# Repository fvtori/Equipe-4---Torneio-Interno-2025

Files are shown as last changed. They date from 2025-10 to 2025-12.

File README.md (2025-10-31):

# *Mini Sumô*

Robô desenvolvido para participar do Torneio Interno de Robôs na categoria “Mini Sumô”, organizado pelo projeto G.E.A.R..

## Estrutura do Projeto

Este registro descreve o processo de criação e desenvolvimento da Equipe 4, composta por cinco membros com as seguintes funções:

Fernanda — Gestora do projeto

Kirisawa — Veterano auxiliar, responsável pela parte técnica, estrutura e fluxo de montagem

Andresa — Programação

Luan — Eletrônica

Rebeca — Estrutura mecânica

## Organização dos Diretórios
```
CATEGORIA_DO_ROBÔ_ANO/
├── code/                       # Implementação da programação
│
├── docs/                       # Documentação do código
│
├── electronics/                # Eletrônica do projeto
│
├── mechanics/                  # Mecânica do projeto
│
├── misc/                       # Miscelânea
│
├── simu/                       # Simulação 
│
└── README.md --> ESTE ARQUIVO  # Resumo geral dos diretórios
```

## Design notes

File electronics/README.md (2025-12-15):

# Diretório de Eletrônica

Este diretório contém todos os arquivos relacionados ao projeto eletrônico do robô *(categoria do robô)*, incluindo:

- Esquemáticos eletrônicos  
- Diagramas de conexão  
- Lista de componentes (BOM)  
- Datasheets dos componentes  
- Registros de testes  
- Configurações de hardware  

---

## Estrutura

- `img/`: Pasta contendo imagens do projeto eletrônico  
  - Fotos das placas  
  - Diagramas de ligação  
  - Esquemáticos em protoboard/PCB  

---

## Documentação

Este README contém as instruções de uso, pinagem utilizada e explicação do circuito da versão atual do robô.

---

# Documentação da Parte Eletrônica — Mini Sumô (Jack)

O sistema eletrônico do robô **Jack**, desenvolvido pela **Equipe 4** para o **Torneio Interno de Robôs 2025** do projeto **G.E.A.R.**, é responsável pelo **controle, alimentação e acionamento dos motores** durante as partidas.

A eletrônica tem como objetivo principal permitir o **controle remoto via Bluetooth**, por meio de um **controle 8BitDo**, utilizando a biblioteca **Bluepad32** conectada à **ESP32 DevKit**.

Na versão atual do projeto, foi adotada novamente a **placa de expansão roxa da ESP32**, pois ela facilitou a organização das conexões e permitiu uma montagem elétrica **mais compacta**, adequada ao espaço reduzido do chassi do robô.

O sistema é alimentado por uma **bateria de lítio 2S (~7,4 – 7,8 V)**, responsável por fornecer energia tanto para os motores quanto para a parte lógica.

A **ponte H utilizada é a L298N**, responsável exclusivamente pelo **acionamento e controle dos motores DC**.

A **alimentação da ESP32 não é feita pela saída de 5V da L298N, como estava sendo feita antes**.  
A ESP32 é alimentada diretamente pela bateria através da **placa de expansão**, que possui **regulador onboard**, responsável por adequar a tensão de entrada aos níveis corretos de operação do microcontrolador.

Além disso, foi incluído no circuito um **módulo carregador de bateria de lítio**, permitindo a recarga da bateria sem a necessidade de desmontar o robô.

O sistema conta ainda com:
- um **interruptor (switch)** geral;
- um **fusível único** de proteção;
- um **buzzer** para sinalização sonora.

Os motores utilizados são **motores DC N20 com caixa de redução**, escolhidos por serem mais leves e compatíveis com o limite de peso da competição.

Essa versão representa a **arquitetura final da eletrônica do robô**, utilizada na fase de competição.

---

## ⚙️ Componentes Principais do Sistema Eletrônico

| Componente | Quantidade | Função no Circuito | Observações |
|---|---|---|---|
| **ESP32 DevKit** | 1 | Comunicação Bluetooth e controle do robô | Biblioteca Bluepad32 |
| **Placa de expansão roxa (ESP32 Expansion Board)** | 1 | Organização das conexões e regulação de tensão | Regulador onboard |
| **Ponte H L298N** | 1 | Controle dos motores DC | Dois canais independentes |
| **Motores DC N20 com redução** | 2 | Tração do robô | Leves e eficientes |
| **Bateria de lítio 2S (7,4 – 7,8V)** | 1 | Fonte de energia principal | Alimenta todo o sistema |
| **Módulo carregador de bateria** | 1 | Recarga da bateria | Integrado ao circuito |
| **Interruptor (switch)** | 1 | Liga/desliga geral | Corte total da alimentação |
| **Fusível** | 1 | Proteção elétrica | Protege a linha principal |
| **Buzzer** | 1 | Sinalização sonora | Controlado por GPIO |
| **Cabos e fios** | — | Interligações elétricas | Curtos e organizados |

---

## 🔌 Alimentação e Ligações de Energia

O robô **Jack** é alimentado por uma **bateria de lítio 2S (7,4 – 7,8V)**.  
A distribuição de energia é feita de forma direta e compacta utilizando a **placa de expansão da ESP32**.

### 🔋 Caminho da alimentação

1. **Bateria 2S (7,4 – 7,8V)**  
2. **Interruptor (switch)**  
3. **Placa de expansão da ESP32**  
4. Distribuição da energia para:
   - ESP32 (via regulador onboard)
   - Ponte H L298N
   - Demais periféricos

Todos os módulos compartilham **GND comum**, condição essencial para o correto funcionamento dos sinais de controle.

---

## 🔒 Fusível (Proteção)

O circuito utiliza **um único fusível**, instalado após o switch, responsável por proteger a alimentação principal e a ponte H contra curto-circuito e sobrecorrente.

---

## 🧠 Resumo da Alimentação

| Elemento | Alimentação |
|---|---|
| ESP32 | 7,4 – 7,8V (via placa de expansão) |
| Ponte H L298N | 7,4 – 7,8V |
| Motores N20 | 7,4 – 7,8V |
| Buzzer | Linha lógica |
| Módulo carregador | Conectado à bateria |

---

## 🧩 Pinagem e Conexões Lógicas — ESP32 + L298N

As conexões lógicas entre a **ESP32** e a **ponte H L298N** seguem o mapeamento abaixo.

---

### 🔵 Canal A — Motor Esquerdo

| Ponte H | GPIO ESP32 | Função |
|---|---|---|
| ENA | GPIO 23 | PWM (velocidade) |
| IN1 | GPIO 19 | Direção |
| IN2 | GPIO 18 | Direção |

---

### 🔴 Canal B — Motor Direito

| Ponte H | GPIO ESP32 | Função |
|---|---|---|
| ENB | GPIO 22 | PWM (velocidade) |
| IN3 | GPIO 5 | Direção |
| IN4 | GPIO 21 | Direção |

---

### 🔔 Buzzer

| Componente | GPIO ESP32 | Função |
|---|---|---|
| Buzzer | GPIO 32 | Sinalização sonora |

---

## ⚡ Observações Importantes

- ENA e ENB utilizam **PWM** para controle de velocidade.
- IN1 a IN4 definem o sentido de rotação dos motores.
- O buzzer é utilizado para sinalizar quando o controle conecta na esp32
- O compartilhamento de **GND comum** é essencial para o funcionamento correto do sistema.

---

## 📌 Resumo Rápido da Pinagem

| Componente | GPIO |
|---|---|
| ENA | 23 |
| IN1 | 19 |
| IN2 | 18 |
| ENB | 22 |
| IN3 | 5 |
| IN4 | 21 |
| Buzzer | 32 |

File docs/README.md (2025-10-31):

# **docs**
Este diretório tem como objetivo documentar o projeto do código do robô do seu grupo. É o relatório de todo o projeto.

O código implementado pode ser visto em: [`code`](../code).
## **Introdução**

O projeto se trata de um robô *(categoria do robô)* de alto desempenho utilizado para a competição *(nome da competição)*.

<!-- *Imagem/ do robô* -->
<!-- ![Nome do robô](img/nome_do_arquivo_de_imagem.png)  -->

*Figura 1: *(categoria do robô)**

## **1. Bill of Materials (BOM)** 

**(*Apenas um exemplo, adicionar coisas como motor, microcontrolador, pneu, etc*)**

Na tabela a seguir será possível observar a lista com todos os componentes físicos utilizados para a construção do robô *(categoria do robô)*:

| 	| **Bill of Materials - BOM** 	| 	|
|:---:	|:---:	|:---:	|
| Nome 	| Explicação 	| Quantidade 	|
| 	| **Baterias e componentes relacionados** | 	|
| Bateria X 	| Bateria do robô 	| qtd 	|
| 	| **Componentes eletrônicos** 	| 	|
| Sensor X 	| Sensor para X coisa 	| qtd 	|
| Componente Y 	| Componente para Y coisa | qtd 	|

## **2. Modelagem 3D**

*Inserir imagens e explicações da [modelagem 3D](../mechanics)*.

## **3. Esquemático eletrônico**

*Inserir imagens e explicações do [circuito eletrônico](../electronics)*.

## **4. Arquitetura geral do diretório raiz**

- **[/code](../code)** — Código-fonte do robô: firmware, bibliotecas, scripts de build e exemplos de execução.
- **[/docs](../docs)** — Documentação do projeto: relatórios, manuais, diagramas e este README.
- **[/eletronics](../eletronics)** — Esquemáticos, listas de componentes (BOM), layouts de PCB e notas de montagem.
- **[/mechanics](../mechanics)** — Modelos 3D, desenhos CAD, arquivos de impressão/usinagem e instruções de montagem mecânica.
- **[/misc](../misc)** — Arquivos diversos: qualquer arquivo que não se enquadram nas demais pastas. (editais, planilhas, etc)
- **[/simu](../simu)** — (OPCIONAL) Cenários de simulação, scripts de execução e automação, ferramentas de visualização.

Cada pasta contém um README interno com instruções específicas de uso, dependências e explicações específicas.

## **5. Organização do Fluxo do Robô (Exemplo)**

1. **Setup:**
    - Inicializar sensores, motores, PID, e conexão remota.

2. **Loop Principal: (Exemplo)**
    - Ler sensores.
    - Calcular o erro da linha.
    - Ajustar a velocidade com o PID.
    - Detectar faixas indicativas e curvas.
    - Analisa eventos para mapeamento.
    - Enviar dados para telemetria.
    
3. **Comunicação Bluetooth:**
    - Escutar comandos remotos para ajuste do PID.
    - Enviar dados em tempo real.

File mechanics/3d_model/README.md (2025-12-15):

# Modelagem do Robô

Este documento descreve o modelo mecânico do robô, apresentando as peças desenvolvidas, suas funções e a estrutura geral do conjunto.

---

## 1. Modelo Inicial

O modelo inicial é composto por um chassi que abriga dois motores de alto torque (JGA), conectados a duas rodas por meio de engrenagens cônicas. A transmissão do movimento e a fixação das rodas utilizam um conjunto formado por bucha, arruela, rolamento e parafuso.

### Função de Cada Componente

- **Base (Chassi):**
<div align="center">
  
</div>

  Abriga motores, rodas e partes do sistema de transmissão.

- **Engrenagem Cônica:**
  
<div align="center">
  
 </div>

  Transmite o movimento do motor para a roda que mantêm uma relação de 90°.

- **Bucha:**

  <div align="center">
  
  </div>
  
  Mantém o espaçamento correto entre o rolamento e a parede interna do chassi.

- **Arruela:**
  
  <div align="center">
  
  </div>

  Auxilia na fixação e na distribuição da carga da roda.

- **Rolamento:**
  <div align="center">
    
 </div>

  Permite o giro suave da roda e conecta o eixo ao conjunto de engrenagem.

- **Montagem:**
  <div align="center">
    
  </div>

  Montagem completa da base
- **Rampa:**
  <div align="center">
    
     </div>

O modelo conta com um protótipo de rampa na parte frontal, integrada ao chassi, projetada para auxiliar o robô durante seu deslocamento e interação com obstáculos.

---

## 2. Montagem Final

Após a mudança do motor JGA para o N20, foi necessário modificar a base a fim de atender aos requisitos do sumô. 
O chassi abriga dois motores de torque médio (N20), conectados a duas rodas. É composto por duas camadas: a primeira camada envolve os motores, as rodas e a case de pilhas, enquanto a segunda acomoda a ponte H, a placa de expansão da ESP32 e a própria ESP 32. A rampa se manteve a mesma.

- **Primeira camada (Base do chassi):**
   <div align="center">
     
     </div>

  Abriga motores, rodas e case.

- **Segunda camada:**
   <div align="center">
     
     </div>

  Abriga ponte H e placa de expansão.

- **Montagem completa:**
   <div align="center">
     
     </div>

- Primeira camada
<div align="center">
  
</div>

- Segunda Camada vista por baixo
<div align="center">
  

</div>

## 3. Arquivo de Montagem

A visualização completa do robô montado pode ser encontrada em:

**`Montagem.iam`**

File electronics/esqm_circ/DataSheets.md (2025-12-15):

# 📄 Datasheets — Componentes do Circuito Eletrônico Oficial  
## Robô Mini Sumô Jack (Equipe 4 — G.E.A.R.)

Este documento reúne os *datasheets e referências técnicas oficiais* dos componentes utilizados no *circuito eletrônico final* do robô *Jack*.

Os links apresentados servem como base para:
- consulta técnica;
- verificação de limites elétricos;
- especificações de pinagem;
- futuras manutenções ou melhorias no projeto.

---

## 📑 Lista de Datasheets

| Componente | Datasheet / Referência Técnica |
|---|---|
| *ESP32 DevKit (ESP32-WROOM)* | https://www.mouser.com/datasheet/2/891/esp-wroom-32_datasheet_en-1223836.pdf |
| *Placa de Expansão ESP32 (Expansion Board)* | https://handsontec.com/dataspecs/module/ESP/ESP32%20Expansion%2030P.pdf |
| *Ponte H L298N* | https://www.handsontec.com/dataspecs/L298N%20Motor%20Driver.pdf |
| *Motor DC N20 com redução* | https://www.pololu.com/file/0J1487/n20-micro-metal-gearmotors.pdf |
| *Bateria de lítio 2S (Li-ion / LiPo)* | |
| *Módulo carregador de bateria de lítio (TP4056)* | https://www.circuits-diy.com/tp4056-battery-charger-module/ |
| *Buzzer ativo 5V* | https://www.farnell.com/datasheets/2171929.pdf |
| *Interruptor (Switch ON/OFF)* | https://components101.com/switches/spst-rocker-switch-non-illuminated |
| *Fusível (vidro / automotivo)* | https://pt.scribd.com/document/430928597/a90-fusiveis-termicos|

---

## 📌 Observações

- Alguns componentes (como motores N20, buzzers e interruptores) possuem *variações de fabricante*.  
  Os datasheets listados representam *modelos equivalentes amplamente utilizados*.
- Este arquivo complementa:
  - README.md — funcionamento e arquitetura do circuito  
  - BOM.md — lista oficial de materiais  
  - historico_circuitos.md — evolução do circuito eletrônico

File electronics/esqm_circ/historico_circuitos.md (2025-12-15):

# Histórico de Desenvolvimento do Circuito — Robô Jack

Este documento mostra a evolução do circuito eletrônico do robô **Jack**, desde as primeiras versões de teste até o modelo final utilizado na competição.

---

### 🧪 Circuito Teste 1

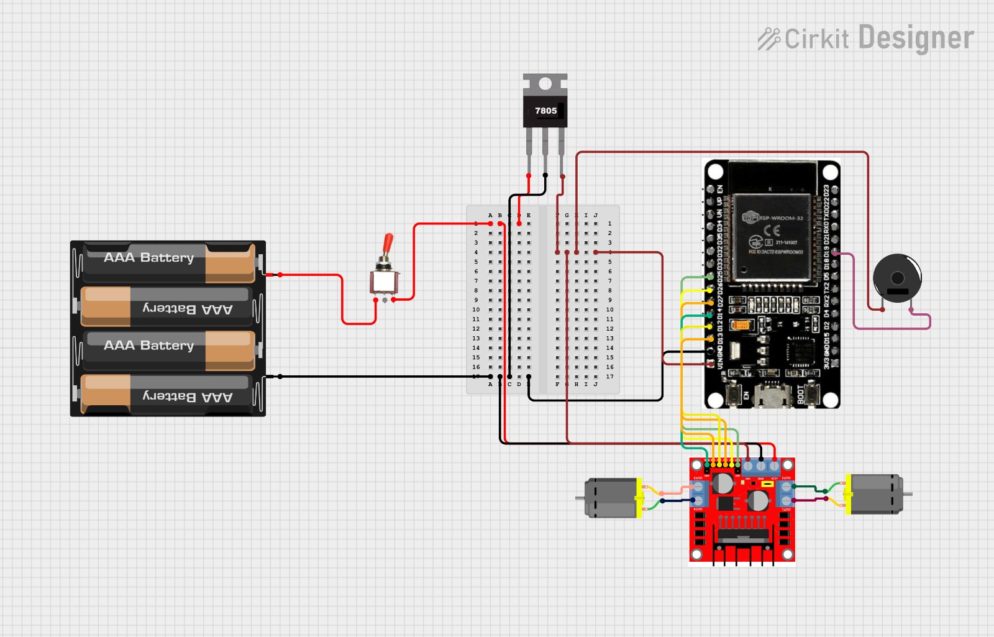
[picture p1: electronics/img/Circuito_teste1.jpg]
Circuito introdutório - versão inicial


O primeiro circuito desenvolvido para o robô **Jack** teve como principal finalidade **representar conceitualmente o sistema eletrônico** do projeto.  
Nesta etapa, ainda não foram realizados testes práticos, com o objetivo sendo apenas **visualizar e planejar** como seria feita a distribuição de energia e o controle básico dos motores.

A proposta dessa montagem foi criar uma **referência visual** que ajudasse a equipe a entender o caminho da alimentação e a função de cada componente, antes de partir para a execução real do protótipo.

#### 🧩 Estrutura e componentes representados
- **Case de 4 pilhas AAA**: escolhido inicialmente para fornecer aproximadamente **9 V**, simulando uma fonte simples e acessível.  
- **Chave liga/desliga (switch)**: adicionada para representar o controle manual de energia.  
- **Regulador de tensão 7805**: responsável por reduzir a tensão de 9 V para 5 V, garantindo segurança à ESP32.  
- **Protoboard**: utilizada como base para a montagem ilustrativa, permitindo visualizar o trajeto dos fios e conexões.  
- **Ponte H (L298N)**: incluída para simular o controle bidirecional dos dois motores DC.  
- **Buzzer**: adicionado como indicação sonora de funcionamento.  
- **ESP32**: microcontrolador principal, representando o núcleo lógico do sistema.

#### 🎯 Objetivo da versão
O propósito desta primeira versão foi **explorar visualmente a arquitetura elétrica** do robô, definindo:
- Como a energia fluiria desde o case de pilhas até a ESP32;  
- Onde seriam posicionados os componentes principais;  
- E como os motores e o buzzer seriam integrados ao controle lógico.

---

### ⚙️ Circuito Teste 2 — Planejamento para Transição à PCB

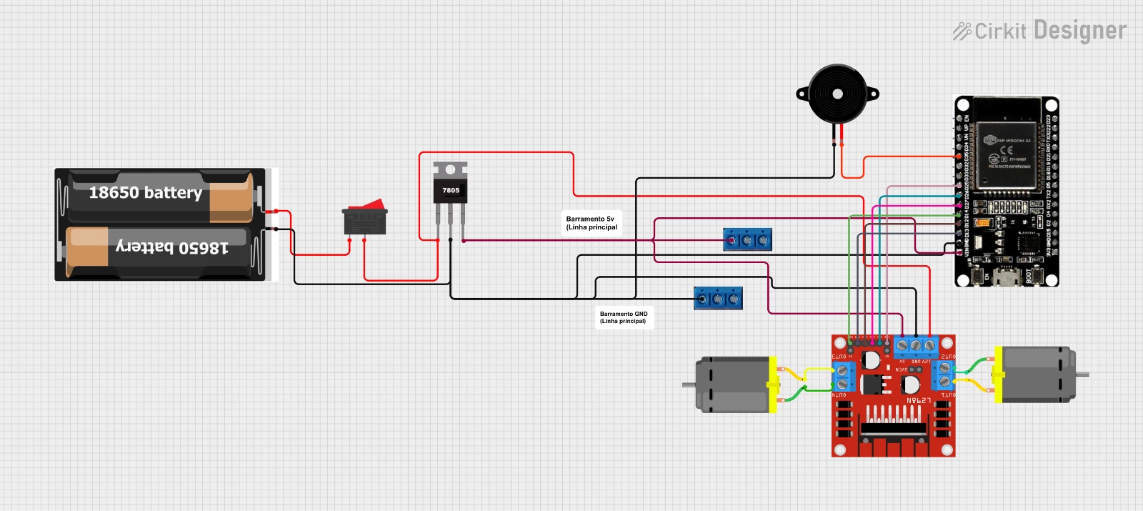
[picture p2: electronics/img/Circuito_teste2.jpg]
Circuito Teste 2


Nesta segunda etapa, a equipe buscou **aperfeiçoar o planejamento elétrico** do robô **Jack**, avançando do modelo conceitual inicial para uma proposta **mais estruturada e realista**.  
A principal mudança foi a **intenção de substituir o uso da protoboard por uma placa PCB personalizada**, onde os componentes seriam soldados, garantindo maior confiabilidade durante a competição.

O esquema apresentado representa esse novo conceito de organização e distribuição de energia. Embora o circuito não tenha sido montado fisicamente, ele serviu como **base de estudo para o design da futura placa**.

#### 🔧 Estrutura e componentes representados
- **Bateria 18650 (2 unidades em série)**: substituiu o antigo case de pilhas AAA, fornecendo uma **tensão nominal de 7,4 V** e maior autonomia.  
- **Chave liga/desliga (switch)**: manteve-se como controle principal de alimentação.  
- **Regulador de tensão 7805**: responsável por fornecer **5 V estáveis** para o circuito lógico.  
- **Barramentos VCC e GND**: representados pelos terminais azuis, planejados para fazer parte da futura **PCB**, permitindo a distribuição de energia de forma organizada e segura.  
- **Ponte H (L298N)**: utilizada para controle dos dois motores DC.  
- **Buzzer**: mantido como dispositivo sonoro auxiliar.  
- **ESP32**: microcontrolador principal, responsável pela lógica e controle dos motores.  

#### 🎯 Objetivo da versão
O objetivo desta fase foi **planejar a implementação física definitiva do circuito**, simulando:
- A disposição dos componentes sobre a placa;  
- A criação de **barramentos integrados de 5 V e GND**;  
- A eliminação de fios soltos e conexões instáveis típicas de protoboards.  

A ideia era que a futura PCB concentrasse **toda a parte elétrica principal**, incluindo a ESP32, o regulador, os conectores dos motores e o buzzer.

#### ⚙️ Desafios e decisões
Apesar de o conceito ser promissor, a equipe identificou algumas dificuldades práticas:
- O **tamanho da placa** seria considerável, aumentando o peso e a complexidade do robô;  
- O **processo de soldagem** exigiria tempo e precisão elevados;  
- O número de fios e trilhas seria grande, o que aumentava a chance de erro e dificultava a manutenção.

Esses fatores levaram à decisão de **não prosseguir com o uso da PCB** neste estágio, concentrando esforços em buscar uma solução mais compacta e funcional para a alimentação e distribuição de energia.

---

### ⚙️ Circuito Teste 3 — Implementação de Proteções e Uso do Expansor da ESP32

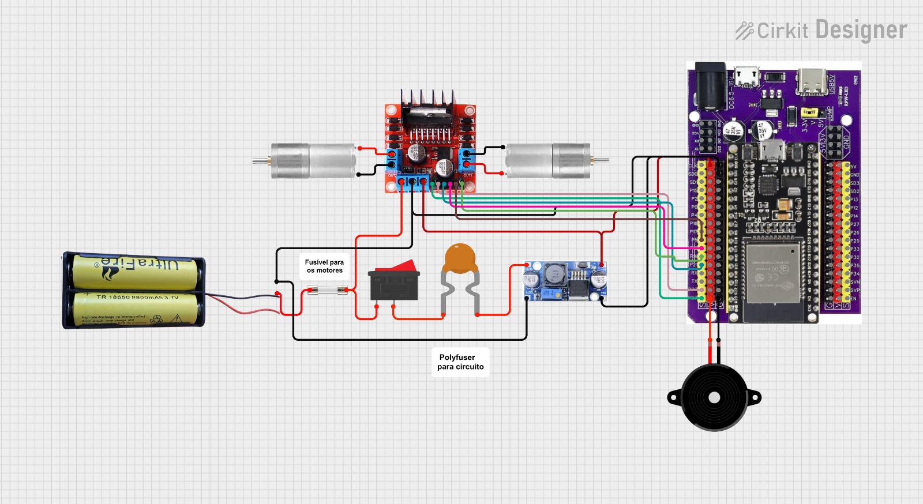
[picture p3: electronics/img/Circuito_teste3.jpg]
Circuito Teste 3


O **Circuito Teste 3** marcou uma das maiores evoluções no projeto eletrônico do robô **Jack**.  
Nesta versão, a equipe focou em **otimizar o espaço físico, melhorar a segurança elétrica e reduzir a quantidade de fios**, aproximando o design do formato que seria utilizado no protótipo final.

Diferente das versões anteriores, este circuito já apresenta uma **configuração mais realista e organizada**, com elementos de proteção e componentes atualizados conforme a disponibilidade no laboratório G.E.A.R.

#### 🔧 Principais mudanças e melhorias
- **Regulador de tensão LM2596:** substituiu o antigo **7805**, já que este não estava disponível no laboratório. O LM2596, além de ser **ajustável e mais eficiente**, dissipa menos calor e garante maior estabilidade.  
- **Interruptor compacto:** adotado no lugar da chave *switch* tradicional, oferecendo **menor consumo de espaço** e melhor integração ao corpo do robô.  
- **Duas medidas de proteção:**  
  - **Fusível** entre a bateria e a **ponte H**, evitando sobrecorrente nos motores;  
  - **Polyfuse (PTC resetável)** em série com o circuito lógico, protegendo a **ESP32 e o regulador** contra curtos e aquecimentos.  
- **Expansor da ESP32:** substituiu a placa simples, funcionando como **protoboard integrada**, o que **reduziu a quantidade de fios** e **facilitou as conexões** de sensores e drivers.  
- **Buzzer** mantido como componente auxiliar de sinalização, agora ligado diretamente ao expansor.

#### 🔋 Organização da alimentação
O novo arranjo manteve o uso de **duas baterias 18650 (7,4 V totais)** como fonte principal, agora com melhor distribuição:
1. A energia passa primeiro pelo **interruptor principal**;
2. Em seguida, é direcionada ao **fusível dos motores** e ao **polyfuse do circuito lógico**;
3. O **regulador LM2596** reduz a tensão para o valor ideal da ESP32 e demais módulos.

Essa configuração tornou o sistema mais seguro, evitando riscos de sobrecarga e incêndio — um passo importante para garantir confiabilidade durante o torneio.

#### ⚙️ Considerações do design
Além das melhorias elétricas, esta versão trouxe uma grande vantagem mecânica: a **eliminação da protoboard**.  
Com o expansor da ESP32, todas as conexões ficaram mais firmes, reduzindo o risco de mau contato e simplificando o layout geral do robô.  

A equipe também pôde visualizar de forma mais clara a **separação das linhas de potência e lógica**, o que facilita futuras manutenções e diagnósticos.

---

### ⚙️ Circuito Teste 4 — Compactação Máxima e Uso de Placas de Servo como Drivers

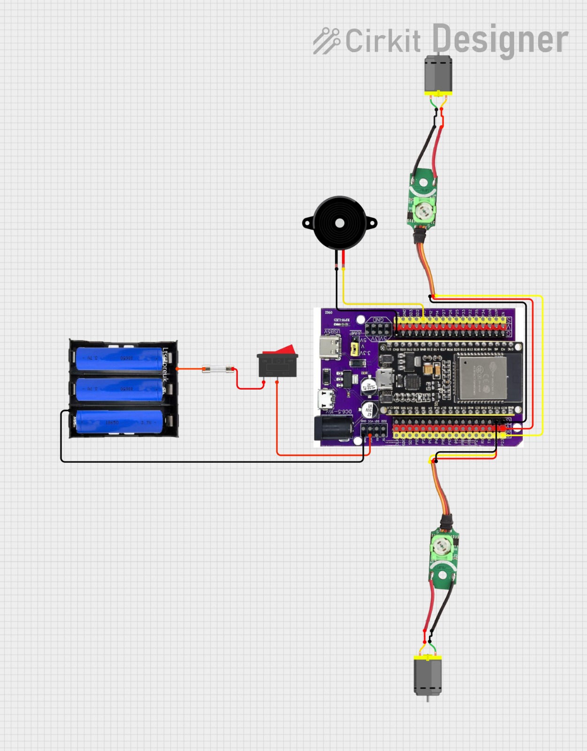
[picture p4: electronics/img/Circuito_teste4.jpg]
Circuito Teste 4


O **Circuito Teste 4** foi desenvolvido como uma tentativa de **reduzir ao máximo o peso e o volume da eletrônica**, priorizando simplicidade e integração direta com o chassi do robô **Jack**.  
Nesta versão, a equipe buscou eliminar componentes considerados intermediários e avaliar soluções alternativas para o acionamento dos motores.

Diferente das versões anteriores, este circuito foi **montado e testado integralmente**, permitindo observar o comportamento real do sistema sob carga.

#### 🔧 Principais mudanças em relação ao Circuito Teste 3
- **Remoção completa do regulador externo (LM2596):** a alimentação passou a utilizar exclusivamente o **regulador onboard da placa de expansão da ESP32**, reduzindo peso e número de componentes.  
- **Alimentação direta no expansor:** o positivo e o GND da bateria foram ligados diretamente aos **pads inferiores da placa de expansão**, simplificando o caminho da energia.  
- **Substituição da ponte H:** a L298N foi removida e substituída por **duas placas de servo modificadas**, cada uma responsável por acionar um motor DC.  
- **Redução de cabeamento:** com menos módulos intermediários, o circuito passou a utilizar fios mais curtos e em menor quantidade.  

#### 🧩 Estrutura do circuito nesta versão
- **Case de 3 pilhas AA**, utilizado como fonte de energia nesta etapa de testes;  
- **Interruptor liga/desliga**, responsável por energizar todo o sistema;  
- **Placa de expansão roxa da ESP32**, centralizando alimentação e sinais;  
- **ESP32 DevKit**, responsável pelo controle lógico;  
- **Duas placas de servo modificadas**, atuando como drivers simples de motor;  
- **Dois motores DC com redução**, utilizados para ensaios de tração;  
- **Buzzer**, mantido para sinalização sonora.

#### 🔋 Organização da alimentação
A alimentação seguiu uma topologia direta e simplificada:
1. A energia das pilhas passa pelo **interruptor principal**;  
2. O positivo e o GND são conectados diretamente aos **pads da placa de expansão**;  
3. O regulador onboard do expansor fornece as tensões necessárias para a ESP32;  
4. Drivers e buzzer compartilham o **GND comum** do sistema.

#### ⚠️ Limitações observadas nos testes
Apesar de o circuito apresentar funcionamento elétrico estável, os testes práticos revelaram uma limitação crítica:

- As **placas de servo modificadas não forneceram corrente suficiente** para os motores DC;  
- O sistema apresentou **baixo torque**, especialmente em situações de maior carga;  
- O desempenho obtido seria insuficiente para aplicações de **mini-sumô**, onde força e resposta rápida são essenciais.

Devido a essas limitações, o **Circuito Teste 4 não foi adotado como solução final**, servindo apenas como etapa experimental.

#### ⚙️ Considerações finais desta etapa
O Circuito Teste 4 foi importante para demonstrar que:
- A **compactação extrema da eletrônica é viável**, desde que os drivers sejam adequados;  
- O uso de soluções reaproveitadas (como placas de servo) pode funcionar em testes leves, mas **não atende às exigências mecânicas da competição**;  
- A escolha do driver de motor é determinante para o desempenho global do robô.

Os aprendizados obtidos nesta versão direcionaram a equipe para uma solução mais robusta na etapa seguinte do projeto.

---

### ⚙️ Circuito Teste 5 — Retorno à Ponte H e Reorganização para Redução de Peso

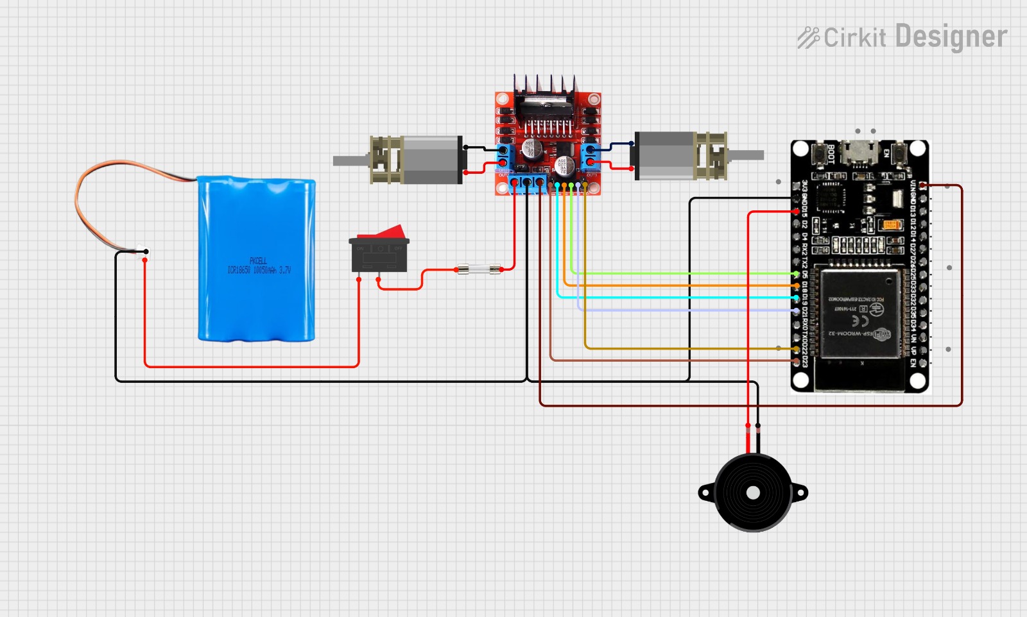
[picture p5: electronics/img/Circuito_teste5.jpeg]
Circuito Teste 5


O **Circuito Teste 5** marca a transição definitiva para uma solução **mais robusta de acionamento dos motores**, corrigindo as limitações observadas no Circuito Teste 4.  
Nesta etapa, a equipe realizou mudanças estruturais importantes, motivadas principalmente por **problemas de torque, confiabilidade elétrica e restrições severas de peso do chassi**.

Embora a imagem apresentada já utilize **motores N20**, este circuito nasceu em um contexto onde ainda eram utilizados **motores maiores (JGA25-370)**, o que influenciou diretamente as decisões iniciais de simplificação extrema da eletrônica.

#### 🔧 Principais mudanças em relação ao Circuito Teste 4
- **Remoção das placas de servo modificadas:** abandonadas devido à incapacidade de fornecer corrente e torque adequados para os motores em condições reais de combate.  
- **Retorno da ponte H L298N:** reintroduzida como solução de acionamento mais confiável e robusta para os motores DC.  
- **Eliminação da placa de expansão da ESP32:** nesta fase, optou-se por ligar a ESP32 diretamente no terminal 5V da ponte h , buscando reduzir peso e volume da eletrônica.  
- **Uso de um único fusível:** toda a proteção passou a ser feita por **um fusível em série**, conectado da chave diretamente à ponte H.  
- **Simplificação da alimentação:** redução do número de módulos intermediários para minimizar massa e pontos de falha.

#### 🧩 Estrutura do circuito nesta versão
- **Bateria de lítio 2S (≈ 7,4 – 7,8 V)** como fonte principal;  
- **Interruptor liga/desliga**, responsável por energizar todo o sistema;  
- **Fusível único**, instalado entre a chave e a ponte H;  
- **Ponte H L298N**, responsável pelo controle dos dois motores;  
- **ESP32 DevKit**, conectada diretamente à ponte H;  
- **Motores DC**, inicialmente JGA25-370 e posteriormente substituídos por **N20**;  
- **Buzzer**, mantido como dispositivo de sinalização.

#### 🔋 Organização da alimentação
A alimentação foi reorganizada de forma mais direta:
1. A energia da bateria passa pelo **interruptor principal**;  
2. Em seguida, atravessa **um único fusível**, responsável pela proteção do sistema;  
3. A tensão é aplicada diretamente à **ponte H L298N**;  
4. A ESP32 é alimentada a partir do circuito principal, compartilhando **GND comum** com a ponte H.

#### ⚠️ Observações importantes desta etapa
- A **remoção da placa de expansão** foi motivada exclusivamente por preocupações com **peso**, não por limitações funcionais;  
- Durante este período, quase foi adotada uma versão definitiva **sem a placa de expansão**, mesmo após a troca dos motores para N20;  
- A imagem apresentada já reflete uma versão **atualizada com motores N20**, embora o conceito original tenha surgido quando ainda se utilizavam motores maiores.

#### ⚙️ Considerações do design
O Circuito Teste 5 foi essencial para demonstrar que:
- A **ponte H é indispensável** para aplicações que exigem torque e resposta rápida;  
- A busca por redução de peso precisa ser equilibrada com **confiabilidade elétrica**;  
- Algumas simplificações extremas, embora tentadoras, podem comprometer a evolução do projeto;  
- A escolha correta dos motores influencia diretamente toda a arquitetura eletrônica.

Este circuito serviu como **ponte de transição** entre as soluções experimentais e a definição da arquitetura elétrica final do robô.

---

### 🏁 Circuito Final (Oficial) — Versão para Competição

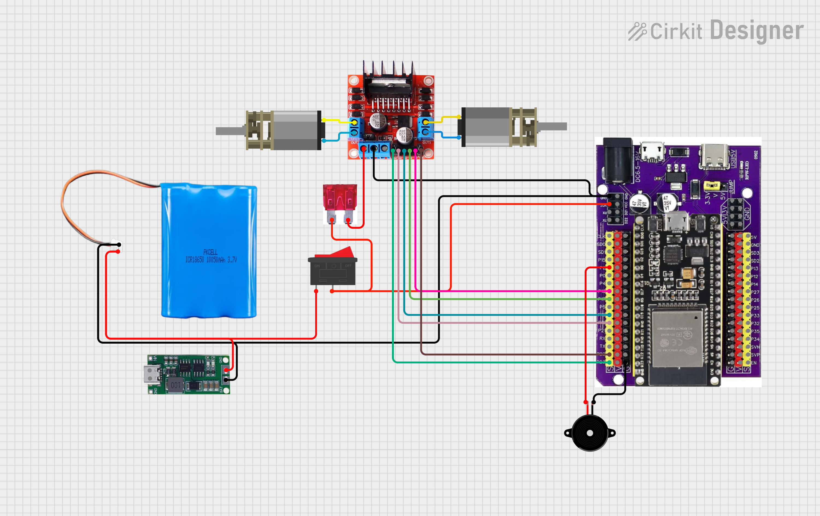
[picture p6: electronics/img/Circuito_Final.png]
Circuito Final


O *Circuito Final* representa a consolidação de todas as decisões técnicas tomadas ao longo do desenvolvimento do robô *Jack, unindo **robustez elétrica, organização física e praticidade de uso* para a competição de mini-sumô.

Com a definição definitiva do uso dos *motores DC N20, tornou-se necessário **reavaliar o balanceamento de peso do robô*, garantindo tração suficiente sem comprometer a confiabilidade do sistema eletrônico.  
Dessa forma, algumas soluções anteriormente descartadas foram *reintroduzidas de forma estratégica*.

#### 🔧 Principais ajustes em relação ao Circuito Teste 5
- *Retorno da placa de expansão da ESP32:* reintroduzida para:
  - auxiliar no *balanceamento de peso* do robô;
  - organizar melhor a distribuição de VCC, GND e sinais;
  - aumentar a robustez mecânica das conexões durante os combates.
- *Manutenção da ponte H L298N:* definida como driver definitivo dos motores N20, garantindo torque adequado e resposta confiável.  
- *Uso de um único fusível:* mantido entre a chave e a ponte H, oferecendo proteção suficiente com menor complexidade.  
- *Inclusão de módulo carregador de bateria de lítio:* permitindo a *recarga direta da bateria*, sem a necessidade de fontes externas ou desmontagem do robô.

#### 🧩 Estrutura do circuito final
- *Bateria de lítio 2S (≈ 7,4 – 7,8 V)* como fonte principal;  
- *Interruptor liga/desliga*, controlando toda a alimentação do sistema;  
- *Fusível único*, protegendo o circuito de potência;  
- *Módulo carregador de bateria de lítio*, conectado diretamente à bateria;  
- *Placa de expansão da ESP32*, utilizada como base física e elétrica;  
- *ESP32 DevKit*, responsável pelo controle lógico e comunicação;  
- *Ponte H L298N*, controlando os dois motores DC N20;  
- *Motores DC N20 com redução*, definidos como solução final de tração;  
- *Buzzer*, utilizado para sinalização sonora.

#### 🔋 Organização da alimentação
A alimentação foi estruturada de forma prática e confiável:
1. A bateria alimenta o sistema através do *interruptor principal*;  
2. O circuito de potência passa por *um único fusível* antes da ponte H;  
3. A *placa de expansão* recebe a alimentação e distribui VCC e GND para a ESP32;  
4. O *módulo carregador* permanece conectado à bateria, permitindo recarga sem alterações no circuito;  
5. Todos os módulos compartilham *GND comum*, garantindo estabilidade dos sinais.

#### ⚙️ Benefícios da configuração final
- *Melhor distribuição de peso*, essencial para o desempenho do mini-sumô;  
- *Conexões mais firmes e organizadas*, reduzindo falhas por vibração ou impacto;  
- *Facilidade de manutenção e recarga*, sem desmontagem do robô;  
- *Arquitetura elétrica estável*, adequada às exigências da competição;  
- Aproveitamento equilibrado entre *simplicidade, robustez e funcionalidade*.

O Circuito Final representa a *versão definitiva utilizada na competição, resultado direto dos aprendizados obtidos ao longo de todas as versões de teste, consolidando uma solução confiável, prática e eficiente para o robô **Jack*.

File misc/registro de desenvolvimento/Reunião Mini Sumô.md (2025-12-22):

***Reunião Mini Sumô:***

**Andressa:**

-> O que foi feito?

passou o código para o git e resolver a biblioteca.

-> O que está em andamento?

otimizar o código

-> Existe algum problema?

print na biblioteca

-> Código base foi concluído?

sim

-> A integração com a elétrica foi finalizada?

sim

-> As bibliotecas foram atualizadas?

sim
-> Sugestão: sugiro que se reúna com o Luan para fazer um teste com o circuito aberto, com todos os componentes.OK

**Luan:**

-> O que foi feito?

Testes do circuito para Ponte H.

-> O que está em andamento?

Abrir o circuito

-> Existe algum problema?

sem problemas

-> Decidiu se usaremos placas servo ou ponte H?
Ponte H

-> Atualizou o diagrama elétrico?

não, mas atualizou o git.

-> Foi validado o circuito final?

sim, falta encaixar o buzzer

-> Sugestão: sugiro que se reúna com o Luan para fazer um teste com o circuito aberto, com todos os componentes.

PETG

**Rebeca:**

-> O que foi feito?

Imprimiu o chassi inicial com engrenagem, fez os dois motores funcionarem com pilhas.

-> O que está em andamento?

a parte de cima do robô.

-> Existe algum problema?

Tamanho, ela vai ver de uma outra forma, ela apresentará as modificações para a próxima reunião, de sexta.

-> Modelagem concluída?

não
-> Sugestão: gostaria de ver o chassi pronto no inventor.
não vai dar!!!

**Pergunta final:**

GitHub foi atualizado?

**Teste Geral:**

**-Andressa
-Luan
-Rebeca**

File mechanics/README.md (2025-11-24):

# Diretório de Mecânica
Este diretório contém todos os arquivos relacionados ao projeto mecânico do robô (Mini Sumô), incluindo:

## Conteúdo
```
mechanics/
│
├── 3d_model/ # Modelos 3D das peças com controle de versões
├── drawing/ # Desenhos técnicos, vistas e dimensões
├── assembly/ # Instruções de montagem do robô
├── stl_file/ # Arquivos prontos para impressão 3D
└── README.md # Documentação geral e histórico
```

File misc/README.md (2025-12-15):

# Diretório de Miscelânea

Este diretório contém arquivos diversos que não se encaixam nas outras categorias principais do projeto do robô da categoria mini sumô, incluindo:

- Regulamento da competição
- Planejamento e objetivos da equipe
- Registros da equipe, como foto e vídeos

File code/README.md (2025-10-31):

# code

Este é um template de projeto padrão para desenvolvimento com [PlatformIO](https://platformio.org/). Ele fornece uma estrutura de pastas limpa e organizada, ideal para iniciar seus projetos de sistemas embarcados.

O objetivo deste template é promover as melhores práticas de organização de código, separando a lógica da aplicação, configurações, bibliotecas e testes.

## Estrutura de Diretórios

O projeto está organizado da seguinte forma:

```
code/
├── .pio/               # Arquivos de compilação e firmware (gerado automaticamente, não está no git)
├── .vscode/            # Configurações do editor Visual Studio Code (gerado automaticamente, não está no git)
├── include/            # Arquivos de cabeçalho (.h) globais do projeto
├── lib/                # Bibliotecas privadas (específicas do projeto) e externas
├── src/                # Arquivos de código-fonte (.c, .cpp) da aplicação
├── test/               # Testes unitários para validação do código
├── platformio.ini      # Arquivo de configuração principal do PlatformIO
└── README.md           # Este arquivo de documentação
```

### Descrição

  * `├── .pio/`

      * Este diretório é gerenciado pelo PlatformIO e contém os arquivos de compilação, dependências baixadas e o firmware final (`.bin` ou `.hex`). **Ele deve ser ignorado pelo sistema de controle de versão (ex: .gitignore).**

  * `├── .vscode/`

      * Contém as configurações específicas para o editor Visual Studio Code, como definições do IntelliSense. Também é gerenciado automaticamente.

  * `├── include/`

      * Use este diretório para arquivos de cabeçalho (`.h`, `.hpp`) que precisam ser compartilhados entre diferentes partes do seu código-fonte em `src/`. Um exemplo clássico é um arquivo `config.h` com definições de pinos e constantes globais.

  * `├── lib/`

      * Local ideal para bibliotecas. Cada biblioteca deve estar em sua própria subpasta (ex: `lib/MySensorLib/`). O PlatformIO automaticamente compila e vincula essas bibliotecas ao projeto. É perfeito para encapsular e reutilizar código.

  * `├── src/`

      * O coração da sua aplicação. O código-fonte principal (`.c`, `.cpp`) reside aqui. O arquivo `main.cpp` (ou `main.c`), que contém as funções `setup()` e `loop()`, é o ponto de entrada do programa.

  * `├── test/`

      * Destinado aos testes unitários. O [PlatformIO Test Runner](https://docs.platformio.org/en/latest/advanced/unit-testing/index.html) procura e executa os testes localizados aqui, ajudando a garantir a qualidade e a confiabilidade do código.

  * `└── platformio.ini`
      * Este é o arquivo de configuração mais importante do projeto. Nele você define a placa-alvo (`board`), o framework (`framework`), as bibliotecas de que o projeto depende (`lib_deps`), as opções de compilação (`build_flags`) e as configurações de upload e monitoramento.

## Como Começar

1.  Clone este repositório para sua máquina local.
2.  Abra a pasta do projeto com o Visual Studio Code (com a extensão PlatformIO instalada).
3.  Modifique o arquivo `platformio.ini` para configurar a sua placa e as bibliotecas necessárias.
4.  Comece a desenvolver o código principal no diretório `src/`.

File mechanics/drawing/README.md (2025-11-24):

# Esboço Inicial

Este documento descreve o esboço inicial utilizado como base para o desenvolvimento do design e da temática do robô pela equipe.

---

## 1. Esboço do Robô

### 1.1. Modelo Conceitual

A escolha da temática surgiu a partir do período em que o robô está sendo desenvolvido: o projeto começou no final de outubro — mês associado ao Halloween — e será concluído no início de dezembro, período natalino, quando ocorrerá o torneio interno.

Assim, o robô receberá o nome **Jack**, inspirado no personagem do filme *O Estranho Mundo de Jack*.  
O design do robô (Figura 1) incorpora elementos característicos do personagem, refletindo simbolicamente a transição entre o Halloween e o Natal, representando o período de desenvolvimento e a identidade criativa da equipe.

Os detalhes estéticos finais serão adicionados **apenas após a conclusão dos testes funcionais**, garantindo que nenhum elemento visual prejudique o desempenho do robô.

---

## 1.2. Esboço 2D

Durante a primeira semana, foi desenvolvido um esboço 2D do robô, considerando os critérios de tamanho e peso para robôs da categoria **Mini Sumô**, além das ideias da temática descritas no subtópico 1.1.

A estrutura projetada é composta por duas peças principais:

- **Caixa (Figura 2):**  
  Base estrutural do robô, com comprimento e largura equivalentes.  
  Nas rampas frontal e traseira, foram adicionadas chapas metálicas para aumentar o atrito e melhorar o desempenho durante as disputas.

- **“Gorro” (Figura 3):**  
  Tampa superior que protege os fios e a parte elétrica.  
  Foi desenhado com foco estético para incorporar a temática do personagem Jack.  
  Será firmemente fixado à caixa para evitar deslocamentos ou danos durante as partidas.

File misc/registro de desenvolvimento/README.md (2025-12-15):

# Registro de desenvolvimento

Este diretório contém fotos e vídeos do processo de desenvolvimento da equipe.

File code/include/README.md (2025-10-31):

Este diretório é destinado aos arquivos de cabeçalho do projeto (*header files*).

Um arquivo de cabeçalho é um arquivo que contém declarações C e definições de macro a serem compartilhadas entre vários arquivos de código-fonte do projeto. Você solicita o uso de um arquivo de cabeçalho em seu arquivo de código-fonte do projeto (C, C++, etc) localizado na pasta `src`, incluindo-o com a diretiva de pré-processamento C `#include`.

```c
// src/main.c

#include "header.h"

int main (void)
{
  ...
}
```

Incluir um arquivo de cabeçalho produz os mesmos resultados que copiar o arquivo de cabeçalho em cada arquivo de código-fonte que precisa dele. Essa cópia seria demorada e propensa a erros. Com um arquivo de cabeçalho, as declarações relacionadas aparecem em um só lugar. Se precisarem ser alteradas, podem ser alteradas em um único local, e os programas que incluem o arquivo de cabeçalho usarão automaticamente a nova versão na próxima vez que forem recompilados. O arquivo de cabeçalho elimina o trabalho de encontrar e alterar todas as cópias, bem como o risco de uma falha em encontrar uma cópia resultar em inconsistências dentro de um programa.

Em C, a convenção é dar aos arquivos de cabeçalho nomes que terminam com `.h`.

Leia mais sobre o uso de arquivos de cabeçalho na documentação oficial do GCC:

  * Sintaxe de Inclusão
  * Operação de Inclusão
  * Cabeçalhos de Inclusão Única
  * Inclusões Computadas

[https://gcc.gnu.org/onlinedocs/cpp/Header-Files.html](https://gcc.gnu.org/onlinedocs/cpp/Header-Files.html)

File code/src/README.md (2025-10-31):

Este diretório é destinado aos arquivos de código-fonte do projeto.

O PlatformIO irá compilar automaticamente os arquivos-fonte deste diretório e vinculá-los ao firmware executável no microcontrolador.

O arquivo principal da sua aplicação (por exemplo, `main.cpp`) deve ser colocado aqui.

**Exemplo (`src/main.cpp`):**

```c
#include <Arduino.h>

void setup() {
  // O seu código de inicialização vai aqui, para ser executado uma vez:
}

void loop() {
  // O seu código principal vai aqui, para ser executado repetidamente:
}
```

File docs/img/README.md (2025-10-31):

# img

Adicione aqui os arquivos de mídia (.png, .jpg, .gif, etc)

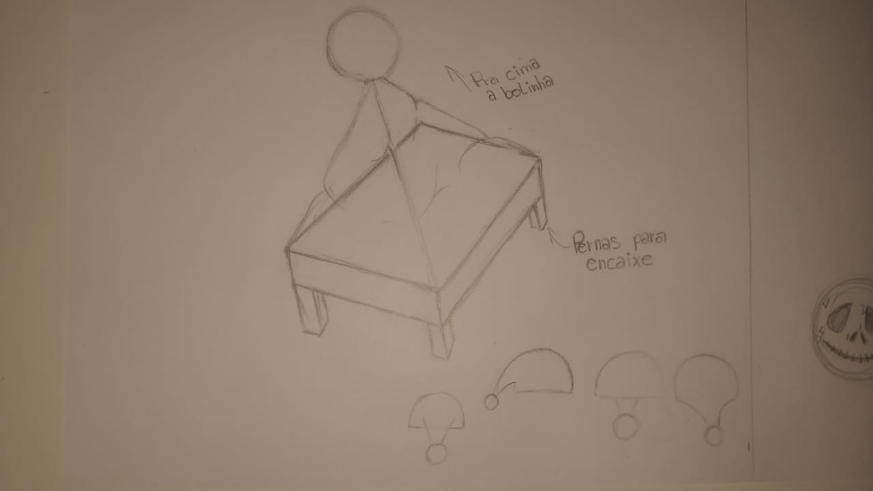
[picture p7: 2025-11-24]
mechanics/drawing/Figura 3.jpeg

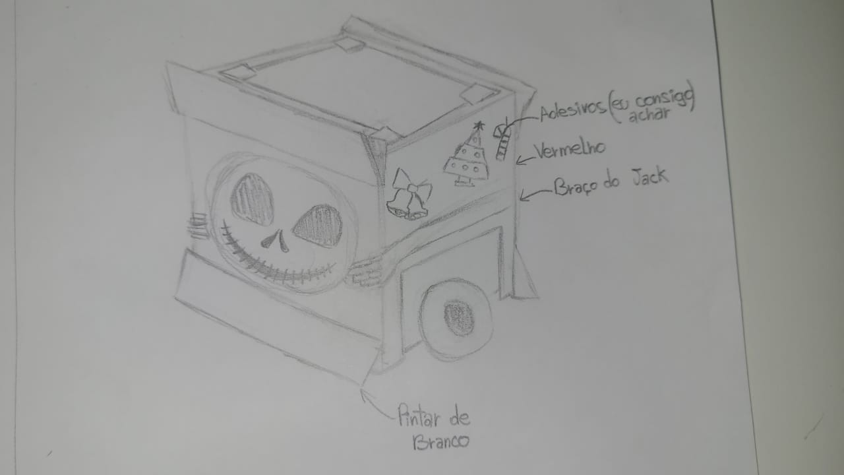
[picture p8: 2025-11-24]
mechanics/drawing/Figura 1.jpeg

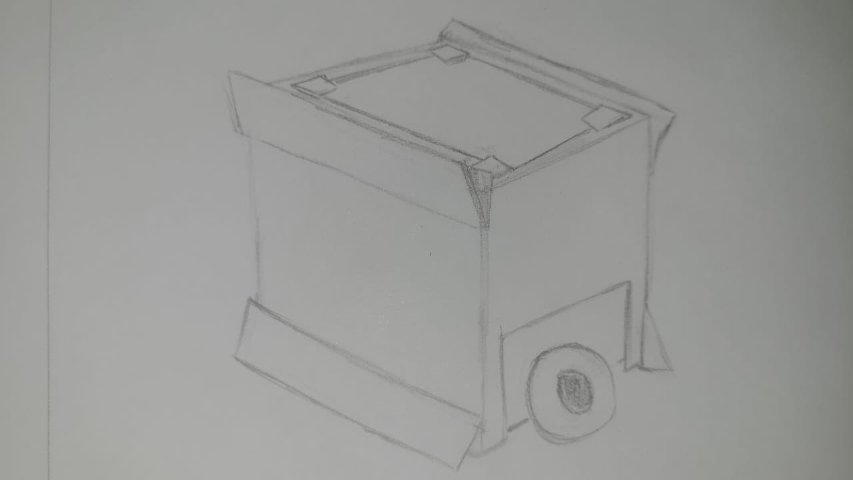
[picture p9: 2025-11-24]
mechanics/drawing/Figura 2.jpeg

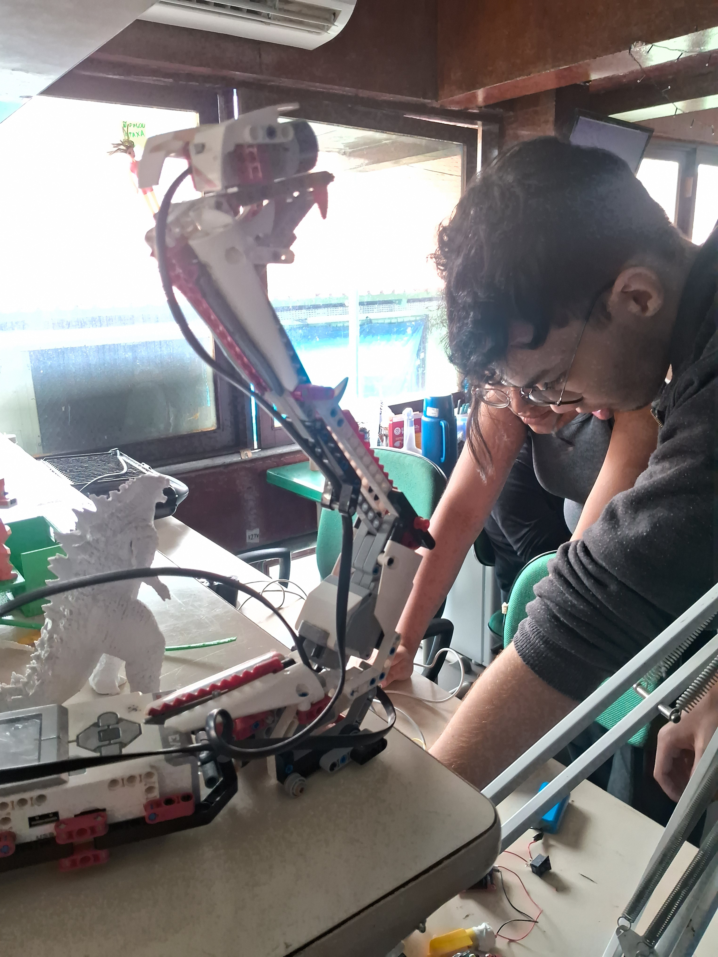
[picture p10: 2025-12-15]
misc/registro de desenvolvimento/Resgistro 2 (19_11).jpg

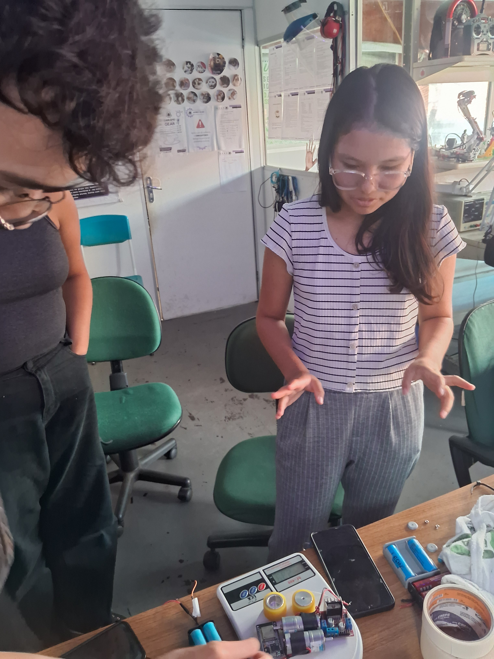
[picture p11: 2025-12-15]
misc/registro de desenvolvimento/Registro (19_11).jpg

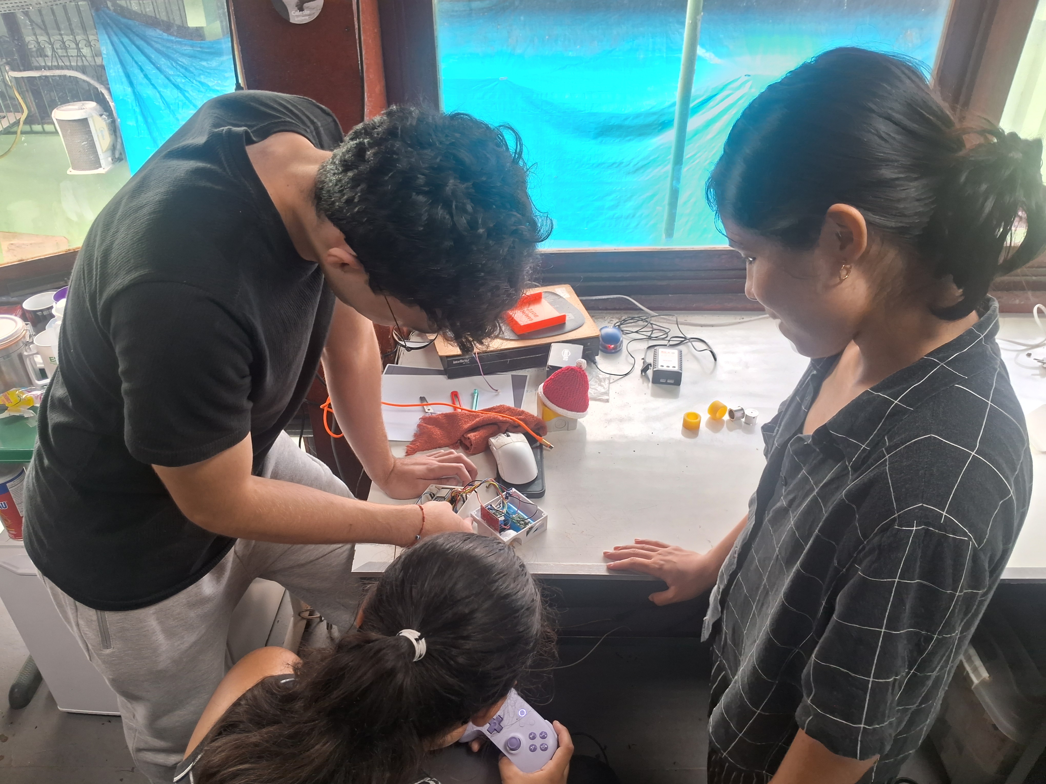
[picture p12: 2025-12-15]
misc/registro de desenvolvimento/Registro 2 (12_12).jpg

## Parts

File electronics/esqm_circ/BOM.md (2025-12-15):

# 🧾 BOM — Bill of Materials  
## Robô Mini Sumô Jack (Circuito Eletrônico Oficial)

Este documento apresenta a **lista oficial de materiais (BOM)** utilizados no **circuito eletrônico final** do robô **Jack**, desenvolvido pela **Equipe 4** para o **Torneio Interno de Robôs 2025 — G.E.A.R.**

O BOM tem como objetivo **documentar tecnicamente** todos os componentes empregados na versão final do circuito, servindo como referência para:
- manutenção;
- replicação do projeto;
- controle e rastreabilidade de componentes;
- consulta técnica futura.

> 📌 **Observação:**  
> Este BOM refere-se **exclusivamente ao circuito eletrônico oficial**, não incluindo versões de teste ou componentes descartados durante o desenvolvimento.

---

## 🔋 Alimentação e Proteção

| Item | Qtd. | Componente | Especificação / Modelo | Observações |
|-----|-----|---|---|---|
| 1 | 1 | Bateria de lítio 2S | 7,4 – 7,8 V | Fonte principal de energia do robô |
| 2 | 1 | Módulo carregador de bateria de lítio | TP4056 (ou equivalente) | Permite recarga da bateria sem desmontar o robô |
| 3 | 1 | Interruptor (switch) | ON/OFF | Corte geral da alimentação |
| 4 | 1 | Fusível | Vidro ou automotivo (corrente compatível) | Proteção da linha principal e da ponte H |

---

## 🧠 Controle e Processamento

| Item | Qtd. | Componente | Especificação / Modelo | Observações |
|-----|-----|---|---|---|
| 5 | 1 | ESP32 DevKit | ESP32-WROOM | Microcontrolador principal do robô |
| 6 | 1 | Placa de expansão ESP32 (roxa) | Expansion Board | Organização das conexões e regulação onboard |
| 7 | 1 | Controle Bluetooth | 8BitDo | Comunicação via Bluetooth utilizando Bluepad32 |

---

## ⚙️ Atuadores e Drivers

| Item | Qtd. | Componente | Especificação / Modelo | Observações |
|-----|-----|---|---|---|
| 8 | 1 | Ponte H | L298N | Driver de potência para dois motores DC |
| 9 | 2 | Motor DC com redução | N20 | Motores de tração do robô |

---

## 🔔 Sinalização

| Item | Qtd. | Componente | Especificação / Modelo | Observações |
|-----|-----|---|---|---|
| 10 | 1 | Buzzer ativo | 5 V | Sinalização sonora do sistema |

---

## 🔌 Conexões e Montagem

| Item | Qtd. | Componente | Especificação / Modelo | Observações |
|-----|-----|---|---|---|
| 11 | — | Fios elétricos | AWG 22–26 | Alimentação e sinais |
| 12 | — | Estanho para solda | — | Fixação permanente das conexões |
| 13 | — | Terminais e jumpers | — | Conexões internas do circuito |

---

## 📌 Observações Finais

- As quantidades indicadas refletem **apenas o circuito eletrônico oficial**.
- Componentes emprestados do laboratório **G.E.A.R.** estão incluídos normalmente para fins de documentação.
- Este BOM não representa uma lista de compras, mas sim um **registro técnico do sistema construído**.
## 📌 Observações Gerais

- Todos os componentes listados pertencem à **versão final do circuito** utilizada na competição.
- A **ESP32 é alimentada pela bateria através da placa de expansão**, que possui **regulador onboard**, não sendo alimentada pela saída de 5V da ponte H.
- O **GND é comum** a todos os módulos (ESP32, ponte H, motores, buzzer e carregador).

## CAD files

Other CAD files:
mechanics/3d_model/Arruela.ipt
mechanics/3d_model/Base.ipt
mechanics/3d_model/Bucha.ipt
mechanics/3d_model/Engrenagem conica 1.ipt
mechanics/3d_model/Engrenagem conica 2.ipt
mechanics/3d_model/Montagem.iam
mechanics/3d_model/Motor.ipt
mechanics/3d_model/Rampa.ipt
mechanics/3d_model/Roda.ipt
mechanics/3d_model/Rolamento.ipt

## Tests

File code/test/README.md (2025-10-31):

Este diretório é destinado ao Executor de Testes (Test Runner) do PlatformIO e aos testes do projeto.

**Testes Unitários** são um método de teste de software pelo qual unidades individuais de código-fonte — conjuntos de um ou mais módulos de programa de microcontrolador, juntamente com seus dados de controle, procedimentos de uso e de operação associados — são testadas para determinar se estão aptas para o uso. Os testes unitários encontram problemas cedo no ciclo de desenvolvimento.

Para mais informações sobre Testes Unitários com o PlatformIO, acesse a documentação oficial:
* [https://docs.platformio.org/en/latest/advanced/unit-testing/index.html](https://docs.platformio.org/en/latest/advanced/unit-testing/index.html)

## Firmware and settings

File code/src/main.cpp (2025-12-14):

#include <Arduino.h>
#include <Bluepad32.h>

// Notas para o Robo Tocar
#define NOTE_C5  523
#define NOTE_D5  587
#define NOTE_E5  659
#define NOTE_F5  698
#define NOTE_G5  784
#define NOTE_A5  880
#define NOTE_AS5 932
#define REST 0

int tempo = 140;

int melody[] = {
  NOTE_C5,4,
  NOTE_F5,4, NOTE_F5,8, NOTE_G5,8, NOTE_F5,8, NOTE_E5,8,
  NOTE_D5,4, NOTE_D5,4, NOTE_D5,4,
  NOTE_G5,4, NOTE_G5,8, NOTE_A5,8, NOTE_G5,8, NOTE_F5,8,
  NOTE_E5,4, NOTE_C5,4, NOTE_C5,4,
  NOTE_A5,4, NOTE_A5,8, NOTE_AS5,8, NOTE_A5,8, NOTE_G5,8,
  NOTE_F5,4, NOTE_D5,4, NOTE_C5,8, NOTE_C5,8
};

int notes = sizeof(melody) / sizeof(melody[0]) / 2;
int wholenote = (60000 * 4) / tempo;
int divider, noteDuration;

bool tocarMusica = false;

//Conectar o Controle e Configurações
ControllerPtr myControllers[BP32_MAX_GAMEPADS];


// Definição dos Pinos
int ENA = 23;  // PWM Motor Esquerdo
int IN1 = 18;  // Esquerdo Frente
int IN2 = 19;  // Esquerdo Trás
int ENB = 22;  // PWM Motor Direito
int IN3 = 17;  // Direito Frente
int IN4 = 16;  // Direito Trás
int BUZZER = 32;


// Controle do Gamepad do Robõ
void processGamepad(ControllerPtr ctl) {
    int RT = ctl->brake();      // Frente
    int LT = ctl->throttle();   // Frente
    bool RB = ctl->r1();        // Trás
    bool LB = ctl->l1();        // Trás

    // Frente
    int pwmRT = map(RT, 0, 1023, 0, 255);
    int pwmLT = map(LT, 0, 1023, 0, 255);

    // Trás
    int pwmRB = RB ? 200 : 0;   // RB só liga / desliga
    int pwmLB = LB ? 200 : 0;   // LB só liga / desliga

    if (RT > 10 || LT > 10) {
        moverF(pwmRT, pwmLT);
    }
    else if (RB || LB) {
        moverT(pwmRB, pwmLB);
    }
    else {
        parar();
    }
}


// Se Controle conectado sinaliza e toca música
void onConnectedController(ControllerPtr ctl) {
    for (int i = 0; i < BP32_MAX_GAMEPADS; i++) {
        if (myControllers[i] == nullptr) {
            myControllers[i] = ctl;

            Serial.printf("Controle conectado! Slot %d\n", i);

            // Ao ligar toca a música
            for (int n = 0; n < notes * 2; n += 2) {

              divider = melody[n + 1];

              if (divider > 0) noteDuration = wholenote / divider;
              else noteDuration = (wholenote / abs(divider)) * 1.5;

              tone(BUZZER, melody[n], noteDuration * 0.9);
              delay(noteDuration);
              noTone(BUZZER);
              }
            delay(noteDuration);
            return;
        }
    }
}
// Se não...
void onDisconnectedController(ControllerPtr ctl) {
    for (int i = 0; i < BP32_MAX_GAMEPADS; i++) {
        if (myControllers[i] == ctl) {
            myControllers[i] = nullptr;

            Serial.printf("Controle desconectado! Slot %d liberado\n", i);
            return;
        }
    }
}



// Funções da Movimentação do Robô
void moverF(int pwmRT, int pwmLT) {
    // Motor esquerdo
    if (pwmRT > 10) {
        digitalWrite(IN1, HIGH);
        digitalWrite(IN2, LOW);
        analogWrite(ENA, pwmRT);
    }
    else {
        analogWrite(ENA, 0);
    }

    // Motor direito
    if (pwmLT > 10) {
        digitalWrite(IN3, HIGH);
        digitalWrite(IN4, LOW);
        analogWrite(ENB, pwmLT);
    }
    else {
        analogWrite(ENB, 0);
    }
}
void moverT(int pwmRB, int pwmLB) {
    // Motor esquerdo
    if (pwmRB > 10) {
        digitalWrite(IN1, LOW);
        digitalWrite(IN2, HIGH);
        analogWrite(ENA, pwmRB);
    }
    else {
        analogWrite(ENA, 0);
    }

    // Motor direito
    if (pwmLB > 10) {
        digitalWrite(IN3, LOW);
        digitalWrite(IN4, HIGH);
        analogWrite(ENB, pwmLB);
    }
    else {
        analogWrite(ENB, 0);
    }
}

void parar() {
    digitalWrite(IN1, LOW);
    digitalWrite(IN2, LOW);
    digitalWrite(IN3, LOW);
    digitalWrite(IN4, LOW);
    analogWrite(ENA, 0);
    analogWrite(ENB, 0);
}


// Musica de Natal
int mIndex = 0;
unsigned long mTimer = 0;

void tocarMusicaAoConectar() {
    if (!tocarMusica) return;
    if (mIndex >= notes * 2) {
        tocarMusica = false;
        noTone(BUZZER);
        return;
    }

    if (millis() >= mTimer) {
        int nota = melody[mIndex];
        int div = melody[mIndex + 1];

        int duracao = (div > 0)
                      ? wholenote / div
                      : (wholenote / abs(div)) * 1.5;

        if (nota == 0) noTone(BUZZER);
        else tone(BUZZER, nota, duracao * 0.9);

        mTimer = millis() + duracao;
        mIndex += 2;
    }
}




// Setup e Loop
void setup() {
  Serial.begin(115200);

  pinMode(ENA, OUTPUT);
  pinMode(IN1, OUTPUT);
  pinMode(IN2, OUTPUT);
  pinMode(ENB, OUTPUT);
  pinMode(IN3, OUTPUT);
  pinMode(IN4, OUTPUT);
  pinMode(BUZZER, OUTPUT);

  parar();

  // Inicia os Controles
  BP32.setup(&onConnectedController, &onDisconnectedController);
  BP32.forgetBluetoothKeys();
}

void loop() {
  tocarMusicaAoConectar();
  
  if (BP32.update()) {
      for (auto ctl : myControllers) {
          if (ctl && ctl->isConnected() && ctl->hasData()) {
                processGamepad(ctl);
            }
        }
    }

    delay(20);
}

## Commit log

2025-11-08 Document main electronic components for Jack robot
    Added a detailed table of main electronic components used in the Jack robot assembly, including their functions and observations.
2025-11-08 Enhance README with ESP32 pinout and connections
    Added detailed pinout and connection information for the ESP32 used in the Jack robot, including motor control and other components.
2025-11-08 Revise pinagem e conexões lógicas da ESP32
    Atualiza a seção de pinagem e conexões lógicas da ESP32 no README, detalhando as ligações e funções dos pinos utilizados no robô Jack.
2025-11-11 Create circuito_final.png
2025-11-11 Rename electronics/img/0096139e-699c-41e1-ada7-8c8e7eefd284.jpg to electronics/Circuito Teste 1.png
2025-11-11 Rename 0096139e-699c-41e1-ada7-8c8e7eefd284.jpg to Circuito teste1.jpg
2025-11-11 Rename 59b1e356-96a7-419f-b97b-85ccd4817eac.jpg to Circuito teste2.jpg
2025-11-11 Rename afb9e1ac-da43-4a5c-9ae9-9bc9f959aa47.jpg to Circuito test3.jpg
2025-11-11 Rename Circuito test3.jpg to Circuito teste3.jpg
2025-11-11 Rename 3c2b040a-32b4-4a0b-9c5d-1118597f02e7.jpg to Circuito Oficial.jpg
2025-11-11 Rename Circuito teste1.jpg to Circuito_teste1.jpg
2025-11-11 Rename Circuito teste2.jpg to Circuito_teste2.jpg
2025-11-11 Rename Circuito teste3.jpg to Circuito_teste3.jpg
2025-11-11 Rename Circuito Oficial.jpg to Circuito_Oficial.jpg
2025-11-11 Update and rename .gitkeep to materials.md
2025-12-15 Rename circuit_image (12).png to circuit_oficial
2025-12-15 Add circuit_oficial.jpg image file
2025-12-15 Rename circuit_image (12).png to Circuito_Oficial.png
2025-12-15 Add files via upload
    O Edital foi usado como guia para o planejamento e desenvolvido do projeto.
2025-12-15 Update historico_circuitos.md with recent changes
    Removed outdated section for Circuito Teste 4 and updated image for Circuito Teste 5.
2025-12-15 Add files via upload
    O arquivo "Planejamento" contém o cronograma de desenvolvimento da equipe e os objetivos de cada Sprint.
2025-12-15 Add files via upload
    O documento "Edital - Torneio Mini Sumo" foi usado como base para o planejamento e desenvolvimento do projeto.
